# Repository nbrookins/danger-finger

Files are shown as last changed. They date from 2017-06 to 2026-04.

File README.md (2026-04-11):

# danger-finger
Source code for the DangerCreations danger-finger, a DIY 3D-printable prosthetic finger device.

This is a pre-release, in progress.  Use at own risk.  Latest stable version is available at: http://www.thingiverse.com/thing:1340624

You'll need to install Python3, and then once you have Python and Pip, do "pip3 install -r ./requirements.txt"
then simply run "python3 utility.py" to compile the project.  It will output a .scad file for each part as well as a composite "all".  If you add the -r flag ("python3 utility.py -r"), it will attempt to locate OpenSCAD on your machine, and render the SCAD files into STL.  Alternatively you can do this manually with each required scad file by performing RENDER and Export STL in OpenSCAD app.

-----------------------------------------------------------------------------------

The project is undergoing a major rewrite, from OpenSCAD to Python 3 + SolidPython2, a drastic improvement in reliable configuration to various shapes and sizes and needs as well as making the codebase easier to maintain and update.

For more information about how to build or have a prosthetic finger built, visit: http://dangercreations.com/prosthetics

**Docs**: [Parameters](docs/PARAMETERS.md) · [Product requirements and design decisions](docs/PRODUCT.md)

**G-code (Anycubic ACE / multi-tool)**: [tools/gcode-swap.py](tools/gcode-swap.py) post-processes exported `.gcode` to insert toolchanges on a repeating schedule (1–4 tools). Use `-n N` for the same layer thickness per color, or `--layers-per-tool n0,n1,…` for different counts per tool in cycle order (e.g. `--tools 0,1,2 --layers-per-tool 8,3,5`). It rewrites `paint_info` so **Color Match** sees distinct RGB swatches (from `extruder_colour` or `--tool-colors`). **Speed**: `--m220-percent` injects `M220 S…` after the first layer (firmware %); `--f-percent` or `--f-factor` scales every `F` feedrate in the executable block (bakes into G-code; composes with `M220` if both are set). **Temperature** (only between the first `;LAYER_CHANGE` and `; filament end gcode`, and only where `S>0` so cooldown is untouched): `--bed-temp`, `--tool-temps 220,225` or `0:220,1:225`. **Inspect**: `--inspect` prints layers, F/M220 stats, temps in that window, and colors. Other flags: `--dry-run`, `--no-flush`, `--no-wipe-tower`, `--no-patch-paint`, `--first-layer`, `--m220-reset-end`. Example: `python3 tools/gcode-swap.py -n 3 --no-flush plate.gcode -o plate_swapped.gcode`

**Web tests**: `make test-web` runs e2e against a fresh server. `make verify-web-ui` starts the server (Docker or local); the server builds SCAD + preview PNGs to `output/` at startup, then captures `output/viewer-screenshot.png`. Use `make build` first for Docker (avoids macOS OpenSCAD issues). For inspect only with an already-running app: `make inspect-ui` (writes `output/ui-inspect.txt`). Requires `pip install -r requirements-dev.txt`, `python -m playwright install chromium`, and OpenSCAD.

**Parametric QA loop**: Create a local env with `python3 -m venv .venv && .venv/bin/pip install -r requirements.txt -r requirements-dev.txt`. The curated first-wave profile matrix lives in `tests/profiles.py`. `make param-audit-scad` runs the multi-profile audit without STL rendering (useful on macOS when local OpenSCAD is broken). `make param-audit` adds STL + bbox checks, and `make param-audit-visual` also renders multi-view PNGs. The audit writes `output/param_audit/report.json` and `output/param_audit/report.md`.

**Auto-run on commit** (optional): To run web tests automatically when you commit changes under `web/`, install the hook: `cp scripts/pre-commit-web-test.sh .git/hooks/pre-commit && chmod +x .git/hooks/pre-commit`.

**OpenSCAD troubleshooting (macOS Apple Silicon)**:
- *"Incompatible processor... neon crc32"* or *"CGLChoosePixelFormat() failed"* — Run the server via Docker: `make build` then `make verify-web-ui`. The server runs in Docker and builds SCAD+PNGs at startup, avoiding macOS OpenSCAD/Qt issues.

#vscode and python extension
python3 -m ensurepip --upgrade
python3 -m pip install --upgrade pip
pip3 install -r ./requirements.txt
brew install docker
make

Run tests
--------

Install pytest if you don't have it already:

    pip3 install pytest

Run tests with:

    pytest -q

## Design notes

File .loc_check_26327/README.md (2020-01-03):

# danger-finger
Source code for the DangerCreations danger-finger, a DIY 3D-printable prosthetic finger device.

This is a pre-release, in progress.  Use at own risk.  Latest stable version is available at: http://www.thingiverse.com/thing:1340624

You'll need to install Python3, and then once you have Python and Pip, do "pip3 install SolidTools"
then simply run "python3 danger_finger.py" to compile the project.  It will output a .scad file, depending on flags and configuration.  By default, it will output all objects to a *preview.scad file.

To view the output install OpenScad from openscad.org, and open the scad file.  It can auto-preview, so that each time you compile the Pytyhon, you'll get an automatic preview.  

Lastly, RENDER the scad which will allow you to export an STL file for your printer.  In the future a web-interface and auto-render script will be provided for automating this part of the process.

-----------------------------------------------------------------------------------

The project is undergoing a major rewrite, from OpenSCAD to Python 3 + SolidPython, a drastic improvement in reliable configuration to various shapes and sizes and needs as well as making the codebase easier to maintain and update.

For more information about how to build or have a prosthetic finger built, visit: http://dangercreations.com/prosthetics

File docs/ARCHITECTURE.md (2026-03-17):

# Architecture

This document describes the system architecture of the danger-finger project: how user measurements become printable prosthetic finger STLs, and how the code is organized.

---

## System overview

```
User (browser)
  │  measurements / parameter values
  ▼
index.html + JS modules (api.js, params.js, viewer.js, app.js)
  │  POST /api/preview  or  POST /api/render
  ▼
server.py (Tornado, port 8081)
  │  config hashing, deduplication
  ▼
build() → DangerFinger.build()
  │  SolidPython2 CSG tree → scad_render() → .scad string
  ▼
Scad_Renderer.scad_to_stl()
  │  subprocess: openscad --export-format binstl -o part.stl part.scad
  ▼
.stl files (binary STL)
  │
  ├──(preview)──→ temp dir → served as /api/preview/temp/{run_id}/{part}.stl
  │
  └──(render)───→ bundle.zip (STL + SCAD + config + LICENSE + README)
                    → S3: render/{cfghash}/bundle.zip
                    → Lambda proxy for browser reads
```

---

## Class hierarchy

```
DangerFingerParams          (finger_params.py)
  │  ~80 Prop descriptors (user-facing parameters)
  │  ~20 computed properties (intermediate_width_, tip_radius, etc.)
  │  Preview config: _preview_position_offsets, _preview_rotate_offsets, etc.
  │  compute_preview_positions(), compute_preview_plug_instances()
  │  validate_params(), get_params()
  │
  ▼
DangerFingerBase            (finger_base.py)
  │  build() — iterates FingerPart enum, calls part_xxx(), applies transforms
  │  _part_composite() — assembles multi-part views (all, explode)
  │  scad_header() — $fa/$fs quality settings
  │  Custom primitives: rcylinder, rcube, rcubecyl, trim, flaredcyl, circular_text
  │
  ▼
DangerFinger                (finger.py)
  │  VERSION = 5.4
  │  Class constants: ANCHOR_OFFSET_DISTAL, TENDON_CUT_ROTATE, etc.
  │  PART_COLORS dict
  │  part_base(), part_tip(), part_middle(), part_linkage(), part_socket(),
  │  part_tipcover(), part_plug(), part_peg(), part_pins(), part_stand(), part_bumper()
  │  Shared primitives: knuckle_outer, knuckle_inner, bridge, bridge_anchor,
  │  socket_interface, tendon_hole, elastic_hole, tip_interface, link_hook, etc.
```

Supporting classes:

| Class | File | Role |
|---|---|---|
| `Prop` | `Params.py` | Descriptor enforcing min/max, metadata (docs, adv, hidden), getter/setter hooks |
| `Params` | `Params.py` | Static utility: CLI parsing, config open/save/apply, env var override |
| `Borg` | `Scad_Renderer.py` | Singleton pattern (shared `_shared_state` dict) |
| `Scad_Renderer(Borg)` | `Scad_Renderer.py` | OpenSCAD subprocess management, parallel rendering, multi-view PNG |
| `FingerServer(Borg)` | `server.py` | S3 client (boto3), brotli-compressed storage, config/profile/bundle CRUD |

Enums (`constants.py`):

| Enum | Type | Purpose |
|---|---|---|
| `Orient` | IntFlag | PROXIMAL, DISTAL, INNER, OUTER, UNIVERSAL, MIDDLE — composable orientation flags |
| `FingerPart` | IntFlag | SOCKET, BASE, MIDDLE, TIP, TIPCOVER, LINKAGE, PLUG, PEG, BUMPER, STAND, PINS, ALL, EXPLODE |
| `BumperStyle` | Enum | NONE, MINIMAL, COVER, FULL |
| `RenderQuality` | Enum | INSANE through STUPIDFAST — controls OpenSCAD $fa/$fs |
| `CustomType` | IntFlag | UI widget hints (SLIDER, DROPDOWN, etc.) |

---

## The Prop descriptor system

`Prop` is a Python descriptor that replaces `@property` for configurable parameters. It stores a default value and enforces min/max bounds on every `__set__`.

```python
class Prop:
    def __set_name__(self, owner, name):
        self.name = name

    def __set__(self, obj, value):
        if self._setter: value = self._setter(self, obj, value)
        setattr(obj, "__" + self.name, self.minmax(value, self._min, self._max))

    def __get__(self, obj, objtype=None):
        if obj is None: return self       # class-level access returns Prop itself
        if self._getter: return self._getter(self, obj, objtype)
        val = getattr(obj, "__" + self.name, None)
        return val if val is not None else self._value  # fall back to default
```

Key behaviors:
- Instance values stored as `obj.__paramname` (name-mangled to avoid collision)
- Class-level access (`DangerFingerParams.intermediate_length`) returns the `Prop` object (used by `get_params()` introspection)
- `get_params(adv=False, allv=True, extended=True)` iterates `Prop` descriptors via `inspect.getmembers` and returns metadata dicts for the frontend
- Custom setters handle enum conversion (e.g., `_bumper_style_setter` converts string to `BumperStyle`)

---

## Build pipeline

### 1. `DangerFingerBase.build()`

```python
for _, pv in FingerPart.__members__.items():
    name = str.lower(pv.name)
    self._parts[name] = self.part(pv)       # calls part_xxx() or _part_composite()
    # Apply print-orientation transforms
    if rotates and not isinstance(rotates, dict):
        temp = rotate(rotates)(temp)         # _rotate_offsets[name]
    if offsets and not isinstance(offsets, dict):
        temp = translate(offsets)(temp)       # _translate_offsets[name]
    temp = flatten(temp)
    self._models[name] = temp.render() if self.scad_render else temp
```

After the loop, a second pass renders each model to SCAD strings via `scad_render()` with quality header ($fa, $fs).

### 2. Per-part methods

Each `part_xxx()` method:
1. Constructs CSG primitives (cylinders, cubes, hulls)
2. Combines them additively and subtractively
3. Returns the final SolidPython2 object (not yet SCAD text)
4. The `build()` loop applies `.render()` which evaluates lazy CSG into a concrete tree

### 3. Print orientation

`_rotate_offsets` (dict of part name -> `(rx, ry, rz)`) rotate each part from its natural assembled orientation into optimal FDM print orientation. This happens in `build()` and affects the exported STL files.

The web viewer reverses this with `_preview_rotate_offsets` (approximate inverse rotations applied in the browser). See `docs/VIEWER_ASSEMBLY.md`.

### 4. SCAD rendering to STL

`Scad_Renderer.scad_to_stl()` calls OpenSCAD via subprocess:
```
openscad --enable manifold --export-format binstl -o part.stl part.scad
```

`scad_parallel()` runs multiple parts concurrently using `asyncio` with configurable `max_concurrent_tasks`. PNG previews can be generated simultaneously using `--preview --imgsize`.

---

## Server architecture

### Tornado handlers

| Route | Handler | Method | Auth | Purpose |
|---|---|---|---|---|
| `/` | `IndexHandler` | GET | No | Serves `index.html` with build-ID-stamped `?v=` cache busters |
| `/api/parts` | `ApiPartsHandler` | GET | No | Part list, version, build ID, preview config |
| `/api/preview` | `ApiPreviewHandler` | POST | No | Async preview: enqueues job at PRIORITY_PREVIEW=-10, returns 202 with job_id |
| `/api/render` | `ApiRenderHandler` | POST | Optional JWT | Queue a full render job; authenticated requests get higher priority |
| `/api/preview/temp/...` | `ApiPreviewTempHandler` | GET | No | Serve temp STL files from disk (local only, not S3) |
| `/jobs/{job_id}` | `JobStatusHandler` | GET | No | Job status: preview results from memory, render jobs from S3 |
| `/render/{cfghash}/status` | `RenderStatusHandler` | GET | No | Render status by content hash |
| `/params/...` | `FingerHandler` | GET | No | Parameter metadata (extended JSON) |
| `/profile/.../config/...` | `FingerHandler` | POST/DELETE | JWT | Save/remove config in S3 profile (ownership enforced) |
| `/profiles/...`, `/configs/...`, `/render/...` | `FingerHandler` | GET | No | S3 read fallback (primary is Lambda) |
| `/(*)` | `StaticHandler` | GET | No | Static files from `web/` |

### Preview vs render

- **Preview** (`/api/preview`): Returns 202 immediately. Job enqueued at PRIORITY_PREVIEW=-10 (always first). Worker runs EXTRAMEDIUM quality, writes STLs to temp dir, stores result in `application.preview_results` (in-memory dict, pruned after 10 min). Frontend polls `/jobs/{id}` until complete. No S3 persistence for preview jobs.
- **Save** (`/profile/.../config/...`): authenticated only. Saves config/profile metadata immediately and does not block on rendering.
- **Render** (`/api/render`): HIGH quality, durable async job that eventually writes `bundle.zip` to S3. Guests may render, but guest jobs are deprioritized and rate-limited.

Both preview and render jobs share the same worker queue. Preview jobs are in-memory only (`application.in_memory_jobs`); render jobs are additionally persisted to S3 for restart recovery. The module-level `_app_ref` provides access to application state from helper functions.

### Config hashing

`package_config_json()` removes default-value params, sorts keys, SHA-256 hashes the JSON. Identical configs always produce the same `cfghash`, enabling deduplication.

### S3 layout

```
configs/{cfghash}           — JSON config (brotli-compressed with "42" prefix)
profiles/{userhash}         — JSON profile with configs map (brotli)
jobs/{job_id}               — durable render job records for polling and restart recovery
render/{cfghash}/status     — latest render status payload for hash-based polling
render/{cfghash}/bundle.zip — ZIP containing STLs, SCADs, config.json, LICENSE, README
```

---

## Frontend architecture

Four vanilla JS modules loaded as global IIFEs (no bundler):

### `api.js` — HTTP client
- XHR-based, three base URLs: `baseurl` (default/relative), `readUrl` (Lambda reads), `renderUrl` (EC2 write/render API)
- `requestPreview()` debounced at 500ms; POST returns 202, frontend polls `/jobs/{id}` every 2s via `_pollPreview()`; superseded previews ignored via `_latestPreviewJobId`
- `saveConfig()` is authenticated profile persistence only; `renderConfig()` queues full renders for guests or logged-in users
- `fetchRenderStatus()` / `fetchJobStatus()` poll durable status through the read path
- `fetchBundleZip()` uses `arraybuffer` responseType for JSZip extraction
- Network errors (status 0) on render endpoints show "server offline" message

### `params.js` — Parameter form
- Renders parameter table from `/params/all` metadata in three sections: Common (params with `Section === "common"`), Standard, and Advanced (collapsible)
- Preset configurations dropdown above Common section (Adult index, Adult pinky, Child index, Adult thumb)
- Per-param reset button (×) shown on modified rows; global "Reset all to defaults" link
- Tracks dirty (unsaved) and changed (differs from default) states per param
- `setRenderDisabled()` controls render button independently from save
- `getCurrentParams()` returns current form values as `{name: numericValue}` dict

### `viewer.js` — 3D viewer manager
- Wraps `StlViewer` (Three.js r160 compatibility wrapper)
- Manages part ID -> mesh mapping, plug instances (IDs 100-103), explode slider
- `applyPreviewConfig()` sets positions/rotations/explode offsets from server
- `updateFromStlUrls()` removes all models and re-adds from new URL map
- `PREVIEW_SKIP_PARTS = { "pins": true }` — pins excluded because composite STL cannot be correctly positioned

### `app.js` — Orchestrator
- Initializes all modules, wires callbacks
- Manages guest draft persistence across the WordPress login redirect via `sessionStorage`
- Splits authenticated `Save` from guest-capable `Render`, polls queued jobs, and resumes save after login
- Render button intelligence: tracks `_lastRenderedCfghash`, disables button when config matches last render
- Iframe detection: shows "Open full page" button when embedded; "Share link" encodes params in URL hash
- `restoreFromHash()` loads config from `#config=...` URL hash on page load
- Profile table includes Status column (Saved/Rendering.../Ready) with polling for active renders
- Quality indicator in preview status: "(draft quality)" vs "(print quality)"
- `loadBundleZip()` fetches ZIP via Lambda, extracts STLs with JSZip, and creates blob URLs

### `stl_viewer.js` — Three.js wrapper
- Compatibility wrapper over Three.js r160 + STLLoader r170 + OrbitControls r170
- Replicates the exact `StlViewer` API used by `viewer.js`
- Transform pipeline: load STL -> bbox center -> rotate (world-axis X/Y/Z) -> set position
- See `docs/VIEWER_ASSEMBLY.md` for transform semantics

---

## Docker

`docker/Dockerfile` is based on `openscad/openscad:trixie.2025-12-15` (Debian with OpenSCAD pre-installed). Python 3 venv with solidpython2, tornado, boto3, brotli. Entry point runs `server.py`.

The container serves both the web UI and performs OpenSCAD rendering. No separate worker process.

---

## Testing infrastructure

| Target | Script | What it tests |
|---|---|---|
| `make test-web` | `scripts/test_web.sh` | Fresh local server, hits /, /api/parts, POST /api/preview |
| `make kbr-test` | Makefile inline | Docker build + run + test |
| `make verify-web-ui` | `scripts/verify_web_ui.sh` | Docker container + Playwright screenshot |
| `make inspect-ui` | `scripts/inspect_ui.py` | Playwright against running server |
| `make reference-stls` | `scripts/reference_stls.py` | Build baseline STL checksums |
| `make regression-check` | `scripts/regression_check.py` | Compare current STLs to baseline |
| `make validate-formula` | `scripts/validate_formula.py` | Sweep params, check geometry |
| `pytest` | `tests/test_*.py` | Unit tests: param sweep, boundary, smoke |

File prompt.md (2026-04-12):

# DangerFinger

Parametric prosthetic finger — a customizable, 3D-printable mechanical finger prosthesis. Users configure parameters through a web UI, preview the assembled model in a Three.js viewer, and download STL files for printing.

## Stack

- **Geometry**: Python + SolidPython2 → OpenSCAD SCAD → STL
- **Web**: Tornado server, Three.js viewer, Playwright for automated visual testing
- **Deploy**: Docker image on EC2 (via ECR), static assets on S3 + CloudFront
- **Testing**: pytest, SCAD hash baselines, parameter sweep audits, multi-angle Playwright screenshots

## Key Entry Points

| Task | Command |
|---|---|
| Start dev services | `make start-dev` (run once in terminal) |
| Run all tests (local) | `make test-parametric` |
| Run fast tests only | `make test-parametric-fast` |
| Start local server | `make serve-local` |
| Visual review only | `make visual-review` (needs running server) |
| Build Docker image | `make build` |
| Deploy to AWS | `make deploy` |

## Testing Philosophy

- **Local-first**: All testing runs natively. Docker is only for deploy.
- **Dev-server pattern**: Run `make start-dev` once in a terminal — this starts an OpenSCAD render server and headless Chromium outside the Cursor sandbox. The pipeline connects via localhost, so all 3 tiers run with zero sandbox prompts.
- **OPENSCAD_EXEC**: Set to `bin/openscad-local` which POSTs to the dev-server's OpenSCAD endpoint. Fallback: `bin/openscad-docker`.
- **Tiered validation**: Tier 1 (fast, no OpenSCAD), Tier 2 (STL render + bbox), Tier 3 (visual web UI via CDP).
- **Artifacts**: `output/parametric-report.md`, `output/visual-review/report.html`, `output/viewer-screenshot.png`.

## Project Structure

- `danger/` — parametric model (finger_params.py, finger.py, finger_base.py, Scad_Renderer.py)
- `web/` — Tornado server + Three.js viewer (server.py, viewer.js, stl_viewer.js)
- `scripts/` — automation (parametric_report.py, visual_review.py, param_audit.py, verify_web_ui.sh)
- `tests/` — pytest suite (param sweeps, profile tests, geometry checks)
- `bin/` — CLI wrappers (openscad-docker)
- `docker/` — Dockerfile + entrypoint for production image
- `infra/` — Terraform for AWS infrastructure
- `docs/` — architecture, deploy, parameters, viewer assembly docs

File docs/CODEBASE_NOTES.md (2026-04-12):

# Codebase Notes

Learnings discovered during SCAD optimization and customizer planning (2026-03-12).

## Geometry and rendering

- `finger.py` contains 12 `part_*` methods and ~38 helper functions (~780 lines)
- `finger_params.py` defines 93 `Prop` parameters (plus 1 in `finger.py`: `peg_hollow_radius`)
- Render quality uses `$fa`/`$fs` globally (set in SCAD header), NOT `$fn`
  - SolidPython2's `_fn=` parameter emits per-primitive `$fn=` which overrides the global setting
  - Mixed `$fn` and `$fa/$fs` can produce visual seams at primitive boundaries
  - Only use `_fn=` on cutting geometry (invisible in final output) or hull anchors (too small to see)
- `RenderQuality.EXTRAHIGH` (value 8) exists in `constants.py` but has NO mapping in the `fs_` or `fa_` dicts in `finger_params.py` -- using it will cause a `KeyError`

## Known hotspots

- `_socket_bottom()` (line 460): loop runs `socket_depth` (default 34) individual `rotate_extrude()` calls -- the #1 render-time hotspot
- `part_tipcover()` fingerprints (line 366): ~19 individual cube subtractions from a sphere
- Bridge/tunnel system (`create_bridge`, `make_bridge`): most complex CSG geometry, uses multi-sphere hulls with small anchor spheres

## Parameter system

- `Prop` class in `Params.py` supports: val, minv, maxv, doc, adv (advanced), hidden, custom (CustomType), setter
- `CustomType` enum (DROPDOWN, SLIDER, SPINNER, CHECKBOX, TEXTBOX) exists but is only used by the web UI, not for SCAD output
- `Params.open_config` does direct `params[k] = config[k]` with no migration path -- if a Prop name changes, saved configs silently fall back to defaults
- No preset/sizing infrastructure exists; must be built from scratch

## Regression testing

- `scripts/regression_check.py` uses exact SHA-256 hashes of STL files
- `scripts/reference_stls.py` generates reference STLs at default params
- Any change to tessellation (quality settings, $fn overrides) will change hashes even when geometry intent is unchanged
- For optimization work, need geometry-aware validation (bounding box, volume, visual diff)

## Magic number audit (Pass 2, 2026-04-11)

Class-level constants in `DangerFinger` and inline literals in `part_*` methods.

### Derived (applied)

| Constant | Old value | New formula | Status |
|---|---|---|---|
| `SCALLOP_HEIGHT` | `9` | `socket_bottom_cut` (property) | Applied. Exact match at defaults. **Visual review needed at extreme socket_bottom_cut** (0–60). |

### Derivation candidates (need visual review before applying)

| Constant | Value | Candidate formula | Match at defaults | Notes |
|---|---|---|---|---|
| `PEG_SUPPORT_RADIUS` | 1.2 | `tendon_hole_radius + 0.1` | Exact (1.2) | Support sleeve around peg hole; would scale with tendon size |
| `PEG_SUPPORT_SIDE_X_OFFSET` | 1.65 | `tendon_hole_radius * 1.5` | Exact (1.65) | Side support spread; proportional to tendon path |
| `PEG_SUPPORT_TRANSLATE_Z` | 3.4 | No clean formula | N/A | Closest: `tendon_hole_width * 1.545` — not clean enough |
| `ANCHOR_OFFSET_DISTAL` | -0.485 | No clean formula | N/A | Closest: `-(knuckle_clearance * 0.5 + knuckle_side_clearance)` = -0.42 |
| `TENDON_CUT_ROTATE` | -80 | Fixed angle | N/A | Empirically tuned cut angle for tendon routing |
| `SOCKET_RIDGE_SPACING_FACTOR` | 0.0015 | Fixed factor | N/A | Controls ridge texture density; print-tolerance dependent |
| `SOCKET_BOTTOM_CUT_FACTOR` | 1.2 | Fixed factor | N/A | Scales bottom cut radius; likely print-tolerance dependent |
| `SCALLOP_RADIUS_ADJ` | 1 | Fixed offset (mm) | N/A | Scallop oversizing; may relate to wall thickness |
| `TIP_FIST_TRIM_ROTATE` | -25 | Fixed angle | N/A | Range-of-motion clearance; empirically tuned |

### Inline method literals (not yet promoted to constants)

| Location | Value | Description | Candidate |
|---|---|---|---|
| `part_base` | `breather_radius_factor=0.2` | Breather hole proportion | Could be Prop if user-meaningful |
| `part_base` | `breather_height=20` | Subtractively long | Could be `socket_depth + margin` |
| `part_base` | `breather_translate_y=-10` | Alignment offset | Likely `-(socket_interface_length + margin)` |
| `part_tipcover` | `TIP_CORE_RESIZE_INSET=2` | Flattening of tip sphere | May relate to `tip_radius` |
| `tip_interface` | `tipcover_chamfer=0.6` | Interface chamfer depth | Could relate to `tipcover_thickness` |
| `part_middle` | `-3.75` in `anchor_db` | Bottom strut Y offset | Likely `-(distal_base_length * 0.625)` at defaults |
| `part_middle` | `1.3` in bumper translate | Bumper X centering | Empirical; tracks hinge radius offset |
| `bridge_anchor` | `-.5` in `height_bottom` | Strut clearance | Small tolerance offset |
| `knuckle_inner` | `1.0` in `anchor_b` Y | Bottom anchor Y nudge | Likely related to clearance |

## Downstream consumers of part output

- `web/server.py` treats stand as a standard part in render/preview flows
- `scripts/generate_static.py`, `scripts/reference_stls.py`, `scripts/regression_check.py`, `scripts/validate_formula.py` all iterate over parts
- Stand exclusion in native SCAD means "don't port it" but keep generating it from Python pipeline

## Existing infrastructure

- `benchmark-ec2` Makefile target exists for cloud benchmarking (no local render-timing target)
- `validate-formula` target exists for parameter sweep validation
- `regression-check` target for STL comparison
- `output/` directory exists and is used for build artifacts

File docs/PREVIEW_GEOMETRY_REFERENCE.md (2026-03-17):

# Preview Geometry Reference

Canonical reference for 3D preview part positioning. Consult before changing any offsets.

## Coordinate system

- **Y** = finger long axis (proximal hinge = Y≈0, distal hinge = Y≈int_len)
- **X** = forward/back (positive = toward palm/front, negative = toward back of hand)
- **Z** = left/right (lateral axis, hinge pin direction)

## Current offsets (default params, int_len=24)

| Part | X | Y | Z | Notes |
|---|-----|---|-----|---|
| socket | 0 | -26  | 0 | Large cylindrical socket, wraps around base bottom |
| base | 0 | -4 | 0 | Proximal hinge at top (Y≈0) |
| middle | 0 | 11 | 0 | Spans proximal→distal hinge, struts + cross-members |
| tip | 1 | 26 | 0 | Distal hinge at bottom (Y≈24), X=1 for slight forward offset |
| tipcover | 0 | 38 | 0 | Dome cap on top of tip |
| linkage  | 0 | -3 | 20  | Tendon routing channel, spans full finger on Z side |
| stand | 0 | -45  | 0 | Display stand, hidden by default |
| bumper | 0.5 | 11 | 0 | TPU ring around middle section; X tested: 0=too back, 0.5=flush, 1=tiny protrude back, 2=too forward |
| plug | inst | inst | inst | 4 instances at hinge faces (see below) |

## Plug instances

| Instance | X | Y  | Z | Rotation |
|---|---|-----|---|---|
| Proximal left  | 0 | 0 | -8.6  | (0, 0, 0) |
| Proximal right | 0 | 0 | 8.6 | (0, 180, 0) |
| Distal left | 0 | 24  | -7.4  | (0, 0, 0) |
| Distal right | 0 | 24  | 7.4 | (0, 180, 0) |

Plugs sit at Y=0 (proximal hinge) and Y=int_len (distal hinge). No Y nudge.

## SCAD-derived bbox centers (ground truth for default params)

Computed by applying inverse-print-rotation to native STL vertices + SCAD "all" offsets:

| Part | SCAD X | SCAD Y | SCAD Z |
|---|---|---|---|
| socket | 0.0 | -25.9  | 0.0 |
| base | 0.5 | -3.9 | 0.0 |
| middle | 1.0 | 11.6 | 0.0 |
| tip | 1.2 | 26.3 | 0.0 |
| tipcover | 0.0 | 39.0 | 0.0 |
| linkage  | 0.1 | -3.1 | 20.0 |
| stand | 0.0 | -45.1  | 0.0 |
| bumper | 0.0 | 0.0 | 0.0 |

Note: bumper SCAD center is (0,0,0) because in SCAD it's at the proximal hinge origin.
In the web viewer, bumper must be at middle_y to wrap around the struts after geometry.center().

## Alignment rules

1. **Bumper X must match middle X.** Both wrap the same strut section. If middle moves on X, bumper follows.
2. **Tip X=1** gives a slight forward lean that matches the hinge geometry. Reducing to 0 makes the tip appear recessed.
3. **Hinge overlaps (5-10mm) are natural.** Fork/socket geometry interleaves at each joint. Don't try to eliminate.
4. **Tipcover sits flush on tip.** The gap between tip Y and tipcover Y should be ~12mm (half of each part's Y extent).
5. **Socket/base overlap is expected.** Socket wraps around the base; the top of socket extends up to near the proximal hinge.

## Rotated bounding box dimensions (after center + preview rotation)

| Part | Y half-height | Total Y extent |
|---|---|---|
| socket | 20.4 | 40.9 |
| base | 9.4 | 18.8 |
| middle | 17.1 | 34.2 |
| tip | 7.1 | 14.2 |
| tipcover | 9.0 | 18.0 |
| bumper | 1.8 | 3.5 |
| stand | 18.1 | 36.3 |
| linkage  | 38.1 | 76.1 |
| plug | 3.2 | 6.4 |

## Change log

| Date | Part(s) | Change | Reason |
|---|---|---|---|
| 2026-03-17 | all | Derived from SCAD part_all | Replace manual guesses with measured values |
| 2026-03-17 | plugs | Removed +1.5mm Y nudge | Plugs were sitting above hinge holes |
| 2026-03-17 | middle | X: 1→0, Y: 12→11 | X protrusion visible from side; gap with base |
| 2026-03-17 | tip | Y: 27→26 | Over-correction squeezed tip between middle and cover |
| 2026-03-17 | tipcover  | Y: 39→38 | Slight gap with tip |
| 2026-03-17 | bumper | X: 2→0→1→0.5 | Tested from back view: X=2 protrudes forward, X=0 protrudes back, X=1 tiny back protrude, X=0.5 flush |

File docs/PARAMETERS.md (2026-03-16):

Parametrized magic numbers
==========================

Several hardcoded numbers in `danger/finger.py` were made configurable via `DangerFingerParams` so you can tune behavior without editing source.

Added parameters (defaults chosen to preserve current behavior):

- `proto_shell_sphere_radius` (default 5)
- `proto_shell_sphere_y_factor_a` (default 3.5)
- `proto_shell_sphere_y_factor_b` (default 10.0)
- `proto_shell_sphere_z` (default 9)
- `proto_shell_cut_cube_x`, `proto_shell_cut_cube_y`, `proto_shell_cut_cube_z` (defaults 30,20,30)
- `proto_shell_cut_translate_y` (default -35)
- `tip_proto_cube_x`, `tip_proto_cube_y`, `tip_proto_cube_z` (8,20,20)
- `tip_proto_translate_x_offset` (default 7)
- `tip_proto_bottom_cut_*` (defaults 10,50,30 and translate_x_offset -0.5)
- `cut_fist_radius_offset`, `cut_fist_h`, `cut_fist_scale_y`, `cut_fist_translate_y1`, `cut_fist_translate_y2`, `cut_fist_translate_z`, `cut_fist_rotate` (control the fist cut geometry)
- `bridge_cut_a_y_offset`, `bridge_cut_b_y_offset`, `bridge_ledge` (control bridge cut translations and ledge)

Usage
-----

Adjust parameters either programmatically (e.g. `finger.proto_shell_sphere_radius = 8`) or through any provided GUI/parameter interface before rendering to experiment with variants.

Preview vs print orientation
----------------------------

- **`_rotate_offsets`** (in `danger/finger_params.py`): Applied at export so STLs are in print orientation for slicing. Do not change for preview display.
- **`_translate_offsets["all"]`**: Used by part_all and assembly; do **not** use for viewer layout or you will break the all.stl output.
- **`_preview_position_offsets`**: Viewer-only positions (part name → (x,y,z)). Used only by the web API for preview; part_all and STL export are unchanged. Proximal→distal along +Y; linkage behind finger (-Z). Tune here to fix stacked preview without touching `_translate_offsets`.
- **`_preview_rotate_offsets`**: Per-part (rx, ry, rz) in degrees applied only in the web viewer so the same STLs appear as an assembled finger. Tune these if preview alignment looks wrong. `middle` is set to `(-90, 50, -90)` (approximate inverse of its print rotation `(90, -50, 90)`; see `docs/VIEWER_ASSEMBLY.md` section 6).
- **`_preview_hidden`** *(planned)*: Set of part names (e.g. `{"stand"}`) hidden by default in the preview UI.
- **`_preview_plug_instances`**: List of four `{ "position": (x,y,z), "rotation": (rx,ry,rz) }` entries for the four plug instances (proximal L/R, distal L/R). Same plug STL is shown four times in the viewer at these positions/rotations so plugs appear in their tip holes.
- **`_preview_position_override`** *(planned)*: Optional overrides on top of `_preview_position_offsets` for a single part (viewer only).

Parameter ordering and sections
-------------------------------

Parameters are displayed in three sections via the `section` and `order` attributes on `Prop`:

- **Common** (`section="common"`): Most-used sizing params shown first in a highlighted section. Order determines display position within the section.
- **Standard** (no section, `adv=False`): All other non-advanced params, sorted by order then name.
- **Advanced** (`adv=True`): Collapsed by default, for parameters that affect print fit.

`get_params()` sorts by `(section_rank, order, name)` where `section_rank` is 0 for "common" and 1 for everything else. The API response includes `Section` and `Order` fields in extended mode.

| Param | Section | Order | Rationale |
|---|---|---|---|
| `intermediate_length` | common | 1 | Primary sizing param |
| `socket_circumference_proximal` | common | 10 | Socket fit (widest) |
| `socket_circumference_distal` | common | 11 | Socket fit (narrow end) |
| `socket_depth` | common | 12 | Socket depth |
| `distal_length` | common | 20 | Tip segment length |
| `distal_base_length` | common | 21 | Tip base length |

All other standard params keep `order=100` (default). Advanced params keep `adv=True`.

Notes
-----

These changes are intentionally conservative: defaults reproduce prior behavior. If you'd like I can continue and parameterize additional hardcoded values (nail cut offsets, tunnel helper constants, and more).

---

See also
--------

- [Architecture](ARCHITECTURE.md) — system pipeline, class hierarchy, build flow
- [Parts Anatomy](PARTS_ANATOMY.md) — physical design of each part and known TODOs
- [CSG Patterns](CSG_PATTERNS.md) — SolidPython2 idioms and custom primitives
- [Viewer Assembly](VIEWER_ASSEMBLY.md) — how the web viewer positions and rotates parts
- [Product](PRODUCT.md) — product requirements and design decisions

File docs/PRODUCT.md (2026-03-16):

# Product requirements and design decisions

This document is the running record of product requirements and design decisions for the Danger Finger project. Update it as the product and architecture evolve.

---

## Product requirements

### Goals

- **Web UI**: View and configure the finger prosthetic (STL) in the browser, change parameters with live preview, filter parts, and save/load configs (with auth where needed).
- **Backend**: Support both quick preview (ephemeral, no S3) and full render (stored in S3); keep operations synchronous with a reasonable timeout (e.g. ≤10 s) and run OpenSCAD on the server (not Lambda).
- **Profiles**: Users can save configs under a profile; profile stores config name → cfghash and history for save-in-place and history.

### User-facing features

- 3D viewer for finger parts (tip, middle, base, linkage, etc.) with part visibility toggles (e.g. checkboxes).
- Parameter form: standard parameters visible by default; advanced parameters in a separate section below when “Advanced” is selected. Parameters show descriptions (from API) and feedback for modified values.
- Explode slider: when non-exploded, parts are positioned as assembled (preview position); when exploded, parts move along explode offsets. Same STLs throughout.
- Save config: name and save under current user profile; triggers sync render and stores bundle.zip (STL + SCAD + config + LICENSE + README) in S3. Download link shown on completion.
- Load saved config: fetches bundle.zip from S3 via Lambda, extracts STLs client-side with JSZip, feeds to viewer. Download reuses cached ZIP blob.
- Remove saved configs from profile list.
- Download ZIP: available per-row in saved configs table and after save/load. Same `render/{cfghash}/bundle.zip` object used for viewer load and download — no re-fetch.
- Preview: on param change (debounced), request preview; viewer updates from temp STL URLs. No S3 for preview.

### Authentication

The app integrates with the WordPress site (dangercreations.com) for user identity.
Anonymous users can preview the finger and download public configs.
**Saving configurations and triggering full renders require a logged-in WordPress user.**

Auth flow:
1. User clicks "Log in" → redirected to `wp-admin/authorize-application.php` on WordPress.
2. WordPress authenticates the user (existing session or login prompt), then redirects back to the app with an Application Password.
3. App exchanges the Application Password for a JWT via `POST /wp-json/jwt-auth/v1/token`.
4. JWT stored in `sessionStorage`; `Authorization: Bearer <JWT>` header sent on all protected requests.
5. Tornado validates the JWT locally using the shared `JWT_AUTH_SECRET_KEY`; no WP round-trip per request.
6. Profile key = `user_nicename` from JWT payload (added via WP filter in `functions-auth.php`).

Protected endpoints (require valid JWT; return 401 with `auth_required: true`):
- `POST /api/render`
- `POST /profile/{userhash}/config/{cfg}` — also enforces that `userhash == jwt.user_nicename`
- `DELETE /profile/{userhash}/config/{cfg}` — same ownership check

Public endpoints: `GET /api/parts`, `GET /api/preview`, `GET /params/*`, `GET /profiles/*`, `GET /configs/*`, `GET /render/*`.

Setup: see `wordpress/dangerfinger-setup/README.md` for WordPress plugin installation,
`wp-config.php` additions, `.htaccess` Authorization passthrough, and PHP filter code.

### Non-goals / later

- Automated cleanup of dereferenced S3 objects (optional later).
- OpenSCAD WASM rendering in Lambda (blocked: openscad-wasm lacks Manifold, 100-660x slower than native).

---

## Design decisions

### Backend

| Decision | Rationale |
|---|---|
| **Async preview via job queue** | Preview now enqueued at PRIORITY_PREVIEW=-10 (always first) in the shared render queue, results stored in-memory (pruned after 10 min), frontend polls via /jobs/{id}. Eliminates the 10s timeout error for slow previews. |
| **OpenSCAD on server (not Lambda)** | Docker image already has OpenSCAD; avoids cold starts and payload limits. Container writes to S3; reads go through Lambda. |
| **Preview STLs in temp dir, not S3** | Previews are ephemeral; avoid S3 churn and cost. |
| **ZIP-only storage: `render/{cfghash}/bundle.zip`** | Single compressed object per config containing all STLs, SCAD, config JSON, LICENSE, README. Used for both viewer load (JSZip extraction in-browser) and download. 63% less storage, 33% less egress, 85% fewer requests vs individual STLs. cfghash immutability means no invalidation needed. |
| **Lambda for S3 reads (API Gateway + Lambda)** | Protects AWS credentials from client. Single Python handler with path-based routing: `/configs/{cfghash}`, `/profiles/{userhash}`, `/render/{cfghash}/bundle.zip`. Presigned URL redirect for ZIPs > 5 MB. SAM template at `template.yaml`. |
| **Profile stores `configs[name] = { cfghash, history }`** | Save-in-place and history without storing full config blob in profile. |
| **`/api/params` and `/api/params/all`** | Explicit routes for parameter definitions; frontend uses these instead of legacy `/params` regex route. |
| **`DangerFinger().params()` as a method (not property)** | Server needs to call `params(adv=..., allv=..., extended=True)`; property cannot take arguments. |
| **Print orientation vs preview display** | STLs are exported in print orientation (rotate_offsets) for slicing. Preview applies preview_rotate_offsets and preview position/explode in the viewer only; no duplicate STLs. |
| **`/api/parts` returns preview config** | Each part includes preview_position, explode_offset, preview_rotation (degrees), and hidden_in_preview so the viewer can display parts as an assembled finger and support explode without changing STL files. Plug is expanded to plug_0..plug_3 (same STL via `stl_part`); linkage uses a preview-only position override so it appears behind the finger/socket. |
| **stl_viewer centers geometry by default** | `stl_viewer.js` calls `geometry.computeBoundingBox()` + `translate(-center)` on load, moving the bbox center to the local origin (replicates old `geometry.center()` behavior). `_preview_position_offsets` must therefore specify the assembled-space bounding box center of each part. See `docs/VIEWER_ASSEMBLY.md`. |
| **stl_viewer rotates around world axis** | `add_model` uses `mesh.rotateOnWorldAxis(axis, angle)` X→Y→Z (world-space pre-multiply, equivalent to old `rotateAroundWorldAxis`). With geometry centered at origin, this rotates each part around its own center. Position from `mod_loaded` is set after rotation. |
| **preview_position_offsets fixed for v5.2+ print rotations** | Positions updated to assembled bbox centers measured from v5.1 STLs. Previously all zeros causing parts to overlap at viewer origin. See `docs/VIEWER_ASSEMBLY.md` section 3.2. |
| **SCAD all reference uses preview_rotate=False** | `preview_rotate = False` is hard-coded. `_part_composite` does NOT apply `_rotate_offsets["all"]`. The all.png is the assembled-orientation reference. |
| **OpenSCAD ARM64 workaround** | On macOS ARM64, Qt runtime check fails. Fix: prepend `arch -x86_64` in `Scad_Renderer.py` (Rosetta). `OPENSCAD_USE_ROSETTA` env var. Headless PNG needs Xvfb. |

### Authentication

| Decision | Rationale |
|---|---|
| **WordPress Application Passwords → JWT exchange** | User authorises the app via WP's built-in `authorize-application.php` (no custom plugin for the OAuth step). The returned Application Password is used exactly once to get a JWT, then discarded. JWT is stored in sessionStorage and validated locally — no per-request WP call. |
| **JWT Authentication for WP REST API plugin** | Standard, well-maintained plugin for issuing JWTs from WP. Secret shared with Tornado via `jwt_secret` env var. |
| **user_nicename as profile key** | WP user_nicename is stable (unlike display name) and URL-safe. Added to JWT payload via `jwt_auth_token_before_sign` filter so Tornado can read it without a WP API call. |
| **Auth disabled in dev (jwt_secret unset)** | When `jwt_secret` env var is empty, `auth.py` accepts any Bearer token and returns a guest payload. Allows local dev without a live WP site. |
| **Profile ownership check on writes** | Tornado verifies that `jwt.user_nicename == userhash` in the URL before writing. Prevents authenticated user A from overwriting user B's profile. |
| **PyJWT >= 2.0** | Version 2.x API (`decode` with `algorithms=[]` required, `options={"verify_aud": False}` for WP plugin). `requirements.txt` pins `PyJWT>=2.0`. |

### Frontend

| Decision | Rationale |
|---|---|
| **JSZip for viewer load from bundle.zip** | Load config fetches single ZIP via Lambda, extracts STLs in-browser (~30-50 ms), creates blob URLs for Three.js viewer. Same blob reused for download — zero re-fetch. |
| **Dual base URLs (`baseurl` / `readUrl`)** | Write operations (preview, save) go to Tornado container. Read operations (configs, profiles, render bundles) go to Lambda via API Gateway. Fallback: `readUrl` defaults to `baseurl` when Lambda is not deployed. |
| **Part visibility via checkboxes** | Clearer than toggle buttons; re-show part using `last_stl_urls` so toggling back on uses current preview URL. |
| **Parameters: Common → Standard → Advanced sections** | Most-used sizing params (6 tagged `section="common"`) appear first in a highlighted "Common" section; standard params follow; advanced params remain collapsed. Deterministic ordering via `Prop.order` and `Prop.section`. |
| **Preset configurations** | Dropdown above Common section with 4 presets (Adult index, Adult pinky, Child index, Adult thumb). Applies common param values and triggers preview. |
| **Per-param and global reset** | Each modified row shows an × button to reset that param to default; "Reset all to defaults" link resets everything. |
| **Render button intelligence** | Render button tracks `_lastRenderedCfghash`; disabled when current config matches last render; re-enabled on param change. Labels: Render / Rendering... / Queued... / Rendered. |
| **Full-page launch and share links** | "Open full page" button shown in iframe context; "Share link" button encodes params in URL hash, copies to clipboard. URL hash restored on load. |
| **Profile table status** | Status column shows Ready/Rendering.../Queued.../Saved per config, with polling for in-progress renders. |
| **Quality indicator** | Preview status shows "(draft quality)" or "(print quality)" based on whether current config has been rendered. |
| **Parameter descriptions from API** | API returns `Documentation` (from param docs); shown as tooltip and optional short description under label. |
| **Modified feedback (badge + row highlight)** | Users can see which params differ from default. |
| **Viewer errors surfaced in UI** | `#viewer_error` and `set_viewer_error()`; try/catch and `stl_viewer.error` reported in status so failures are visible. |
| **Request preview from viewer `ready_callback`** | First preview runs after viewer is ready so models load correctly. |

### DevOps / testing

| Decision | Rationale |
|---|---|
| **`make kbr-test`** | Build, run container in background, then run e2e test against it so we test the real Docker stack. |
| **`USE_EXISTING_SERVER=1` in test script** | Allows hitting an already-running server (e.g. Docker on 8081) without starting a second process. |
| **Test port 8091 when starting server in script** | Avoids clashing with Docker on 8081. |
| **`make inspect-ui` (Playwright)** | Headless browser loads the live UI, captures `#preview_status`, `#viewer_error`, and console; writes `output/ui-inspect.txt`. Exit 1 if the UI shows an error. Use when debugging “error and no preview” or to capture exactly what the page shows. Requires `pip install -r requirements-dev.txt` and `python -m playwright install chromium`. |

---

## Infrastructure & Deployment

The application deploys to AWS using Terraform-managed infrastructure. See [DEPLOY.md](DEPLOY.md) for full details.

**Components**: EC2 (Docker + OpenSCAD, handles writes), Lambda + API Gateway (read-only S3 API), S3 (persistent storage), ECR (image registry).

**Key files**: `infra/*.tf` (Terraform), `.github/workflows/deploy.yml` (CI/CD), `scripts/verify_aws_deploy.sh` (smoke tests), `scripts/aws_audit.py` (account audit), `scripts/benchmark_ec2.py` (instance benchmarking).

**Cursor rules**: `.cursor/rules/aws-deploy.mdc` (deployment safety), `.cursor/rules/terraform-conventions.mdc` (Terraform style). **Skill**: `.cursor/skills/deploy-to-aws/SKILL.md`.

---

## Changelog

- **2026-03** – UX overhaul: async preview queue (preview jobs processed at highest priority, polled by frontend), deterministic parameter ordering with Common/Standard/Advanced sections, render button intelligence (disabled when config matches last render), iframe full-page launch and shareable config links via URL hash, profile table render status column (Saved/Rendering/Ready), per-parameter and global reset-to-defaults, draft vs print quality indicator in viewer status, and preset configurations dropdown (Adult index, Child index, Adult pinky, Adult thumb). New Prop attributes: `order` and `section` for deterministic param display.
- **2026-03** – Anonymous access, authenticated save, durable render queue: WordPress now embeds the configurator for guests, while login is only required to save to a profile. Full renders submit through a durable S3-backed job queue with authenticated-first priority, guest throttling, job polling by `job_id` or `cfghash`, and restart recovery that requeues interrupted work after watchdog/container restarts. Frontend save and render are now separate actions, guest draft state survives the WordPress login redirect, and completed bundles remain downloadable without re-rendering.
- **2026-03** – Monitoring and auto-recovery: added CloudWatch-based EC2 system recovery, a scheduled health-check Lambda that probes `GET /api/parts`, automatic SSM container restart attempts, SNS email alerting, and operator commands for checking health/alarm state.
- **2026-03** – WordPress JWT authentication integration. Login via WP `authorize-application.php` → Application Password → JWT exchange. JWT validated locally in Tornado (`web/auth.py`, `WpAuthMixin`). Protected endpoints: `POST /api/render`, `POST /profile/*/config/*`, `DELETE /profile/*/config/*`. Profile ownership check (user can only write their own profile). Auth UI in app header (login/logout button, user display). `user_nicename` added to JWT payload via WP filter (`wordpress/dangerfinger-setup/functions-auth.php`). WordPress security hardening: user enumeration disabled, EXIF stripped, open registration blocked, `readme.html` blocked. CORS tightened to `WpAuthOrigin` parameter. `PyJWT>=2.0` added to `requirements.txt`. New env vars: `jwt_secret`, `wp_auth_url`, `app_base_url`. See `wordpress/dangerfinger-setup/README.md`.
- **2026-03** – AWS deployment infrastructure: audited and cleaned stale ECS/CloudFormation resources (~$20-26/mo savings), created Terraform configs (VPC, ECR, EC2, Lambda, API Gateway, S3, IAM, optional Route53/ACM), Makefile deploy targets, GitHub Actions CI/CD with OIDC, deployment verification scripts, and Cursor rules/skills. EC2 uses IAM instance profile (no static keys); server.py falls back to default credential chain; app.js reads `window.__READ_URL__` injected at serve time.
- **2026-03** – Save/load/download workflow and Lambda S3 access. Render now produces a single `render/{cfghash}/bundle.zip` containing all STLs, SCAD files, config JSON, LICENSE, and README — no individual STL files in S3. Frontend uses JSZip to extract STLs in-browser for viewer load; same cached blob serves as download (zero re-fetch). Save endpoint returns cfghash so frontend can show immediate download link. Added Lambda function + SAM template (`template.yaml`, `lambda/handler.py`) for S3 read operations (configs, profiles, bundles) via API Gateway — protects AWS credentials from client. Frontend dual base URL (`baseurl` for writes, `readUrl` for reads). Removed legacy S3 queue system (`process_scad_loop`, `queue()`, `.mod` files), `serve_download`, `downloads/` prefix, and individual STL upload code. Saved configs table now has Load/Download/Remove columns. Render status indicator shown during save with Save button disabled.
- **2026-03** – Replaced `stl_viewer.min.js` (StlViewer v1.08 / Three.js r86) with `web/stl_viewer.js`: thin wrapper over Three.js r160 (last UMD build) + STLLoader r170 + OrbitControls r170 (adapted to global scripts). Vendored under `web/vendor/three/`. Transform semantics (centering, world-axis rotation) preserved exactly. `get_model_info` returns `{ pos: [x,y,z] }` array for `inspect_ui.py` compatibility.
- **2026-03** – Fixed viewer assembly: `_preview_position_offsets` set to assembled bbox centers from v5.1 STLs; removed legacy 35° Z from tip/tipcover `_preview_rotate_offsets`. Created `docs/VIEWER_ASSEMBLY.md` documenting stl_viewer behaviour, coordinate system, and OpenSCAD ARM64 workaround. Added `.cursor/rules/fix-preview-positions.mdc`.
- **2026-03** – Four plug instances in preview: one plug STL shown four times (plug_0..plug_3) with per-instance position/rotation so plugs appear in tip holes; linkage preview position override so it displays behind the finger/socket. `/api/parts` expands plug and returns `stl_part` for URL lookup; frontend iterates part list and uses `stl_part` when resolving STL URLs.
- **2026-03** – Preview rotate offsets and preview config: STLs stay print-oriented; viewer applies preview_rotate_offsets, preview_position, and explode_offset from `/api/parts` so preview looks like an assembled finger and explode works without duplicating STLs. Stand hidden in preview by default. Cursor rule to keep docs updated.
- **2026-03** – Initial product/design doc; viewer error surfacing; parameter descriptions; part visibility checkboxes; Standard/Advanced layout; PRD + design decisions captured.

---

## Related documentation

- [Architecture](ARCHITECTURE.md) — system pipeline, class hierarchy, build flow, server, frontend
- [Parts Anatomy](PARTS_ANATOMY.md) — physical design of each part, mechanical connections, materials, known TODOs
- [CSG Patterns](CSG_PATTERNS.md) — SolidPython2 idioms, custom primitives, modeling patterns
- [Parameters](PARAMETERS.md) — parameter definitions, preview vs print orientation
- [Viewer Assembly](VIEWER_ASSEMBLY.md) — how the web viewer positions and rotates parts

## Cursor rules index

| Rule | Scope | Purpose |
|---|---|---|
| `parametric-consistency.mdc` | `finger_params.py`, `finger.py`, `finger_base.py` | Cascade checking, fewer-params principle |
| `csg-modeling-guide.mdc` | `finger.py`, `finger_base.py` | Primitive reference, geometry rules |
| `part-physical-context.mdc` | `finger.py` | Read physical context before modifying geometry |
| `coordinate-systems.mdc` | `finger_params.py`, `finger.py`, `viewer.js`, `stl_viewer.js` | Three coordinate spaces |
| `prop-system.mdc` | `Params.py`, `finger_params.py` | How the Prop descriptor works |
| `fix-preview-positions.mdc` | `finger_params.py`, `server.py`, `index.html` | Empirical fix for viewer preview positions |
| `web-ui-inspection.mdc` | `web/**`, `finger_params.py`, `scripts/*` | Never trust a running server; screenshot verification |
| `scad-preview.mdc` | `finger.py`, `server.py`, `scripts/*` | SCAD preview PNG verification |
| `geometry-validation.mdc` | `finger.py`, `finger_base.py`, `finger_params.py` | Topology checks, `_fn` visibility rule, post-CSG-rewrite checklist |
| `python-to-scad-translation.mdc` | `*.scad` | Transform order, formula, and OpenSCAD constraint pitfalls |
| `testing-and-make.mdc` | `scripts/*`, `Makefile`, `tests/**` | Use project make targets |
| `keep-docs-updated.mdc` | `danger/**`, `web/**`, `scripts/*`, `Makefile` | Keep docs updated on changes |
| `project-routing-map.mdc` | Always | Task-domain routing map — which docs to read for which task |
| `endpoint-state-map.mdc` | Always | Endpoint auth requirements, state locations, multi-instance implications |
| `archive-execution-plans.mdc` | Always | Archive plans to `.cursor/plans/` |

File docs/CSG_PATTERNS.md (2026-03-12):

# CSG Modeling Patterns

This document describes the SolidPython2 idioms and custom primitives used throughout the danger-finger codebase. Read this before modifying geometry code in `finger.py` or `finger_base.py`.

---

## SolidPython2 basics

The project uses [SolidPython2](https://github.com/jeff-dh/SolidPython2), which generates OpenSCAD code from Python. CSG operations:

| Python | OpenSCAD | Meaning |
|---|---|---|
| `a + b` | `union()` | Combine volumes |
| `a - b` | `difference()` | Subtract b from a |
| `a * b` | `intersection()` | Keep only overlap |
| `hull()(a, b)` | `hull()` | Convex hull of a and b |
| `a.rotate((rx, ry, rz))` | `rotate()` | Euler rotation (degrees) |
| `a.translate((x, y, z))` | `translate()` | Move |
| `a.scaleX(f)` / `.resize(...)` | `scale()`/`resize()` | Scale |
| `scad_render(obj)` | — | Generate .scad string |
| `obj.render()` | `render()` | Force evaluation (CSG cache) |

SolidPython2 builds a lazy tree. `.render()` evaluates it, which is important for complex boolean operations (avoids re-computation). The `build()` loop calls `.render()` on each model.

---

## Custom primitives (defined in `finger_base.py`)

### `rcylinder(r, h, rnd=0, center=False)`

Rounded-edge cylinder. Uses `rotate_extrude(offset(r=rnd)(offset(delta=-rnd)(square)))` to create filleted edges.

- `rnd=0`: Falls back to plain `cylinder()`
- Used extensively for hinges, struts, bumpers

### `rcube(size, rnd=0, center=True)`

Rounded-edge cube (4 edges rounded). Intersects a cube with a resized cylinder.

- `round_ratio = (1-rnd) * 1.1 + 0.5` controls how much the cylinder crops
- Used for struts, braces

### `rcubecyl(h, w, l, t, rnd=None, rnd1=None, rnd2=None, center=True)`

Hybrid cuboid-cylinder. The most complex primitive. Creates a rounded shape by hulling two scaled copies of a cylinder:

```python
anchor1 = cy.scaleX(.5).translateX(t / 2.0)
anchor2 = cy.scaleX(.5).translateX(-t / 2.0)
hub = hull()(anchor1, anchor2, cy)
return hub.rotate((90, 0, 0))
```

- `h`: height (cylinder axis), `w`: width (cylinder radius), `l`: length (resize X), `t`: hull offset
- `rnd1`/`rnd2`: Per-side rounding (left half / right half). Allows one end to be round and the other flat.
- Used for bridges and bumper shells

### `trim(x=0, y=0, z=0, center=True, offset=(0,0,0))`

Returns a transform function that intersects the object with a cutting cube. Axes set to 0 get a very large value (10000) so they don't clip.

```python
trim(x=10)(obj)            # functional style
obj.trim((10, 0, 20))      # method style (monkey-patched onto OpenSCADObject)
obj.trim((10, 0, 20), offset=(5, 0, 0))  # offset the cutting cube
```

### `flaredcyl(r, h, fr, fh)`

Flared cylinder using double-offset `rotate_extrude`. Creates a cylinder that widens at one end. Used for hinge inset flares.

### `circular_text(txt, radius, size, thickness, spacing, rot, reverse=False)`

Wraps text around a circle. Each character is positioned at an angle computed from character width heuristics (`WIDTH_ADJUSTMENTS` in `constants.py`). Used on the display stand.

---

## Key modeling patterns

### Hull pair pattern

The most common pattern. Two primitives are hulled together to create a smooth transition:

```python
mod_main = (mod_core + mod_hinge).hull() + (mod_tunnel + mod_core).hull()
```

This creates the base's body by hulling the core cylinder with the hinge, then hulling the tunnel with the core. The `+` combines both hulls into the final shape.

**Why**: Hulling two offset shapes creates a smooth, convex transition that is structurally strong and easy to print. Direct union of complex shapes often leaves internal voids or sharp transitions.

### Subtractive modeling

Most parts follow: build up material, then cut away features.

```python
final = (mod_main + mod_interface
         - mod_plug_cut      # subtract plug holes
         - mod_tip_hole       # subtract peg hole
         - mod_hinge_cut      # subtract hinge clearance
         - mod_pin            # subtract pin hole
         - cut[1].translate(...)  # subtract bridge cut
        ) - mod_extra + mod_washers - mod_pin
```

The order matters: additions first, then subtractions. Some features (like washers) are added after initial subtractions because they need to sit in the clearance zone.

### Orient dispatch pattern

Many methods take an `orient` parameter (an `Orient` IntFlag) and branch on it:

```python
if orient == Orient.PROXIMAL:
    trim_dim = self.intermediate_proximal_height
    trim_z = self.knuckle_width_[Orient.PROXIMAL] - self.knuckle_rounding * 4
else:  # DISTAL
    trim_dim = self.intermediate_distal_height
    trim_z = self.intermediate_width_[Orient.DISTAL]
```

The `orient_pair()` helper creates `{Orient.DISTAL: val, Orient.PROXIMAL: val}` dicts for computed properties that differ by orientation.

`Orient` is an `IntFlag`, so values can be combined: `Orient.PROXIMAL | Orient.OUTER` means "the proximal, outer portion" — used heavily in `bridge()` and `bridge_anchor()`.

### Computed property convention

Properties ending with `_` are computed (read-only):

```python
intermediate_width_ = property(lambda self: orient_pair(
    self.intermediate_distal_width_, self.intermediate_proximal_width_))
tip_radius = property(lambda self: self.tip_circumference / math.pi / 2)
```

These derive from user-facing `Prop` parameters. Never set them directly.

### Color coding

Each `part_*` method applies a `.color(PART_COLORS[name])` at the end:

```python
return final.color(PART_COLORS["base"])
```

`PART_COLORS` maps part names to `[r, g, b]` arrays (0-1 range) used by both OpenSCAD's `color()` command and the web viewer's material colors.

### Debug pattern

During development, `.debug()` (renders as `#` in OpenSCAD = transparent highlight) can be chained on any object:

```python
mod_hinge_cut.debug()  # show this subtraction as transparent
```

Many lines have `#.debug()` comments — these are inactive debug calls that can be re-enabled.

---

## Bridge and tunnel construction

The bridge/tunnel system is the most complex geometry in the codebase. It routes the tendon through the hinge zones.

### `bridge(length, orient, tunnel_width)`

Builds a tendon tunnel for external hinges (base and tip). Uses `bridge_anchor()` to create 8 anchor points (4 positions x 2 sides), hulls them, then subtracts a cylindrical channel.

The orient is composite: `Orient.PROXIMAL | Orient.OUTER` means "proximal end, outer part (base or tip side)".

### `bridge_anchor(orient, length, top, inside, shift, rnd)`

Calculates one anchor point for the bridge hull. Returns a small cylinder or sphere positioned at the correct height, width, and depth for the given orientation. The `shift` parameter mirrors the point across Z (left vs right side).

This method contains the most orientation-dependent branching in the codebase — it handles 8 combinations of orient, top/bottom, inside/outside, and distal/proximal.

### `make_bridge(orient, ...)`

A newer, simpler bridge method using `rcubecyl`. Used by base, tip, and middle (COVER/FULL bumper). Creates a single rounded cuboid, scales it, trims it, and subtracts a cylinder channel.

### `create_bridge(r, length, width, height, ...)`

Middle-section tunnel. Similar to `bridge()` but with different anchor geometry. Has a `sharp=True` mode for simpler variants.

---

## Monkey-patching

`finger_base.py` patches `OpenSCADObject` to add method-style `.trim()`:

```python
from solid2.core.object_base.object_base_impl import OpenSCADObject
OpenSCADObject.trim = _open_scad_trim
```

This allows `obj.trim((x, y, z))` instead of `trim(x, y, z)(obj)`.

---

## Common pitfalls

1. **Modifying a primitive affects all callers**: `rcylinder`, `rcubecyl`, `trim`, etc. are used throughout. Changes to these functions will affect every part.

2. **Hull order doesn't matter, but addition/subtraction order does**: `hull()(a, b)` is the same as `hull()(b, a)`, but `(a + b) - c` is different from `(a - c) + b`.

3. **`.debug()` in production**: Leaving `.debug()` active in a `build()` call makes the part transparent in OpenSCAD previews. The `.debug()` calls are commented out but easy to accidentally uncomment.

4. **`.render()` placement**: Calling `.render()` too early freezes the CSG tree, preventing further boolean operations. The `build()` loop calls it at the right time. Don't add extra `.render()` calls inside `part_*` methods.

5. **Scale vs resize**: `.scaleX(f)` multiplies by factor f. `.resizeX(dim)` sets absolute dimension. `.resize(0, 0, z)` only resizes Z — 0 means "keep original".

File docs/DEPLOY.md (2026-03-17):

# AWS Deployment Guide

## Architecture

```
                              ┌──────────────────────────────┐
┌──────────────┐  HTML/JS/CSS │ S3 static site (always on)   │
│   Browser    │◀────────────▶│ danger-finger-static          │
│              │              └──────────────────────────────┘
│              │
│              │  render POST  ┌──────────────────┐       ┌─────────────┐
│              │──────────────▶│ EC2 (t3a.medium)  │──────▶│ S3 (writes) │
│              │  (can fail)   │ Docker + OpenSCAD  │       │             │
│              │               │ Tornado :8081      │       │             │
└──────────────┘               └──────────────────┘       └──────┬──────┘
       │                                                          │
       │  configs/profiles  ┌─────────────────────┐               │
       └───────────────────▶│ API Gateway (HTTP)  │──▶ Lambda ───▶│ (reads)
                            └─────────────────────┘               │
                                                                  │
          ┌──────────────┐                                        │
          │ ECR (images) │◀── Docker push ────────────────────────┘
          └──────────────┘
```

- **S3 static site (`danger-finger-static`)**: Always-on frontend. Serves HTML, JS, CSS, and baked-in JSON for parts/params. If EC2 is down, the UI still loads and all read features work.
- **EC2**: Runs the Docker container with Tornado web server + OpenSCAD renderer. Handles render API calls (POST /api/preview, /api/render) and writes to S3.
- **Lambda + API Gateway**: Read-only serverless API for fetching configs, profiles, and bundle.zip from S3. Always available.
- **S3 (`danger-finger`)**: Persistent storage for all project data (configs, profiles, rendered bundles).
- **ECR**: Docker image registry. Lifecycle policy keeps last 10 images.
- **Route53 + ACM**: Optional custom domain and HTTPS (not enabled by default).

### Static site URLs

| Endpoint | URL | Use |
|---|-----|-----|
| CloudFront (HTTPS) | `https://d1n87lopz9qnnf.cloudfront.net` | Primary — use this for `DANGERFINGER_APP_URL` in WordPress wp-config.php. Required to avoid mixed-content blocking inside the HTTPS WP page. |
| S3 website (HTTP) | `http://danger-finger-static.s3-website-us-east-1.amazonaws.com` | Direct / debugging only |

The static site is the primary frontend. It loads without EC2. Preview/render calls go to EC2 and degrade gracefully with a "server offline" message when EC2 is down.

## Prerequisites

- AWS CLI v2 configured (`aws configure`)
- Docker Desktop running
- Terraform 1.5+ (`brew install terraform`)
- Python 3.12+ with boto3 (`pip install boto3`)
- Make

## Quick Start

```bash
# First time: initialize Terraform
cd infra && terraform init && cd ..

# Full deploy: build → push to ECR → apply infra → verify
make deploy

# Verify deployment
make verify-aws
```

## Makefile Targets

| Target | Description |
|---|---|
| `make ecr-login` | Authenticate Docker to ECR |
| `make push-ecr` | Build, tag, and push Docker image to ECR |
| `make deploy-infra` | Terraform plan + apply |
| `make deploy-ec2` | Update container on EC2 (SSM) |
| `make deploy-lambda` | Update Lambda function code |
| `make deploy` | Full pipeline: build → push → infra |
| `make verify-aws` | Post-deploy smoke tests |
| `make check-health` | Hit the render server health endpoint directly |
| `make check-monitoring` | Show current CloudWatch alarm states |
| `make audit-aws` | Full account audit |
| `make benchmark-ec2` | Run EC2 instance benchmark |

## Terraform Structure

```
infra/
  main.tf           — Provider, S3 backend
  variables.tf      — Input variables
  outputs.tf        — EC2 IP, API Gateway URL, etc.
  vpc.tf            — Default VPC, security groups
  ecr.tf            — ECR repository + lifecycle
  ec2.tf            — EC2 instance, IAM role, user data
  s3.tf             — S3 bucket config (versioning, access block)
  lambda.tf         — Lambda + API Gateway HTTP API
  dns.tf            — Route53, ACM (conditional)
  github_oidc.tf    — GitHub Actions OIDC (conditional)
  user_data.sh      — EC2 bootstrap script template
  environments/
    dev.tfvars      — Dev environment overrides
    prod.tfvars     — Prod environment overrides
```

## Environment Variables

### EC2 Container

| Variable | Description |
|---|---|
| `S3_BUCKET` | S3 bucket name (default: `danger-finger`) |
| `AWS_DEFAULT_REGION` | AWS region (default: `us-east-1`) |
| `READ_URL` | API Gateway URL for Lambda read API |

### Lambda

| Variable | Description |
|---|---|
| `S3_BUCKET` | S3 bucket name |

### Monitoring / Terraform

| Variable | Description |
|---|---|
| `alert_email` | Email address subscribed to SNS monitoring alerts (optional) |

## IAM

- **EC2**: Uses an IAM instance profile with ECR pull + S3 read/write. No static keys needed.
- **Lambda**: Execution role with S3 read-only (GetObject, HeadObject).
- **GitHub Actions**: OIDC federation — no static keys in CI. Set `github_repo` in tfvars to enable.

## Cost Estimate

| Resource | Monthly cost |
|---|---|
| EC2 t3a.medium (24/7) | ~$27 |
| S3 data bucket (minimal usage) | <$1 |
| S3 static site bucket | <$0.01 |
| Lambda (low volume) | <$1 |
| API Gateway | <$1 |
| Route53 zone (if enabled) | $0.50 |
| **Total** | **~$30** |

## Static Site Deployment

The frontend is served from S3 static website hosting. This provides always-on availability independent of EC2.

```bash
# Generate static JSON + deploy to S3
make deploy-static

# Specify custom URLs (otherwise reads from Terraform outputs)
make deploy-static READ_URL=https://YOUR_API_GW.amazonaws.com RENDER_URL=http://EC2_IP:8081/
```

When EC2 is down, the static site still loads and all read features (configs, profiles, parameter controls) work via Lambda. Only preview/render shows "server offline".

## Benchmarking

Run `make benchmark-ec2` or `python3 scripts/benchmark_ec2.py` to test instance types:

```bash
# Test specific types
python3 scripts/benchmark_ec2.py --types t3a.medium,c6a.large --timeout 2400

# Dry run (print user data script)
python3 scripts/benchmark_ec2.py --dry-run
```

### Benchmark results (2026-03-12, amd64, `latest` image)

| Type | Full render | Single part | Pull | $/hr | $/render | Score |
|---|---|---|---|---|---|---|
| t3a.medium | 40s | 3s | 42s | $0.0376 | $0.00042 | 0.418 ✓ best |
| c6a.large | 20s | 1s | 18s | $0.0765 | $0.00043 | 0.425 |
| c7a.large | 15s | 1s | 14s | $0.1026 | $0.00043 | 0.427 |
| t3a.xlarge | 34s | 2s | 29s | $0.1504 | $0.00142 | 1.420 |

**Score** = `($/hr × full_render_s / 3600) × 1000` — lower is cheaper per render.

**Recommendation**: `t3a.medium` wins on cost-per-render (all renders <45s = well within CPU credit burst window). Single-part preview is 3s on t3a.medium vs 1s on compute-optimized — negligible user-facing difference. The compute-optimized instances (c6a/c7a) offer faster absolute render times if UX latency is priority.

Note: `max_concurrent_tasks=2` in `scad_parallel()` is the **CLI batch rendering default** and does not affect web preview latency — web previews render parts sequentially (one per request). On a t3a.medium, a single tip preview takes ~3s end-to-end.

## Troubleshooting

### EC2 container not starting
```bash
# Check user data execution log
aws ssm send-command --instance-ids INSTANCE_ID --document-name AWS-RunShellScript \
  --parameters 'commands=["cat /var/log/cloud-init-output.log | tail -50"]'
```

### Lambda returning errors
```bash
# Check CloudWatch logs
aws logs tail /aws/lambda/danger-finger-s3-read --since 1h
```

### Terraform state issues
```bash
# List state resources
cd infra && terraform state list

# Remove a resource from state (if manually deleted)
terraform state rm aws_instance.app
```

### Monitoring and auto-recovery

The monitoring stack has two layers:

1. **EC2 system recovery** — CloudWatch alarms on `StatusCheckFailed_System` trigger AWS auto-recovery and send an SNS alert.
2. **Application health check** — a scheduled Lambda hits `GET /api/parts` every 5 minutes. If the request fails twice in a row, CloudWatch alarms send an alert. On each failing invocation, the Lambda attempts `docker restart danger-finger` via SSM.

Setup notes:
- Set `alert_email` in your Terraform variables before applying if you want email alerts.
- After the first apply, AWS SNS sends a subscription-confirmation email. Alerts do not flow until you confirm it.
- The health-check Lambda is intentionally lightweight: it probes the app endpoint without triggering a render job.

Operator commands:

```bash
# Check app health directly
make check-health

# Inspect CloudWatch alarm states
make check-monitoring

# Read health-check Lambda logs
aws --region us-east-1 logs tail /aws/lambda/danger-finger-health-check --since 1h
```

Failure behavior:
- If the EC2 host fails AWS system checks, AWS attempts instance recovery automatically.
- If the instance is up but Tornado/container is unhealthy, the scheduled Lambda attempts a restart through SSM.
- If the app stays unhealthy across consecutive checks, CloudWatch triggers the SNS alert and manual intervention is needed.

### Guest access and render recovery

The configurator now supports anonymous preview and anonymous render submission. Profile saves still require login.

Operational details:
- Full renders are queued as durable job records under `jobs/{job_id}` and mirrored to `render/{cfghash}/status` for hash-based polling.
- Authenticated jobs are dispatched ahead of guest jobs; guests are also rate-limited.
- On restart, the Tornado server scans queued/running jobs and requeues interrupted work. Recovery is whole-job requeue only; it does not resume partial OpenSCAD output mid-file.
- Bundle existence at `render/{cfghash}/bundle.zip` is the final source of truth for completion and dedupe.

Verification notes:
- Verify guest access from the WordPress wrapper, not just the raw app URL.
- Verify that a guest save click redirects to login and restores the draft after JWT callback.
- If testing restart recovery, kill the Tornado process during a queued/running render, let watchdog restart it, then poll the job/status endpoint until it resumes or completes.

## CI/CD (GitHub Actions)

The `.github/workflows/deploy.yml` workflow:
1. **Test**: Build Docker image, run e2e tests
2. **Deploy**: Push to ECR, apply Terraform, update EC2 container
3. **Verify**: Run smoke tests against deployed environment

Requires:
- GitHub repository secret: `AWS_ACCOUNT_ID`
- OIDC: Set `github_repo` in Terraform to enable the IAM role

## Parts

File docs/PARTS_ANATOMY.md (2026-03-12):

# Parts Anatomy — Physical Design of the Danger Finger

This document describes each part of the prosthetic finger from a physical and mechanical perspective: what it does, how it connects to adjacent parts, what material it should be printed in, and which parameters most affect it. Read this before modifying any `part_*` method in `finger.py`.

---

## How the finger works

The Danger Finger is a body-powered prosthetic for people missing a finger at any phalange. The key mechanical principles:

1. **Socket** slides over the remnant finger stub (flexible material for comfort)
2. **Base** snaps into the socket via a ridged cylindrical interface
3. **Middle** connects to the base via a proximal hinge joint
4. **Tip** connects to the middle via a distal hinge joint
5. **Tipcover** (flexible) snaps onto the tip, providing a soft fingertip with fingerprint texture
6. **Linkage** runs from the base, under a bracelet on the wrist
7. **Tendon** (fishing line) threads through tunnels in all segments, attaching to the linkage
8. **Elastic cord** threads through the base, providing the return (extension) force

When the user bends their remnant finger, the base tilts forward in the socket, pulling the linkage. The linkage tension propagates through the tendon, curling the finger naturally at both hinge joints. When the remnant straightens, elastic restores the finger to its extended position.

```
                    ┌──tipcover (flexible, snaps on)
                    │
        ┌───tip─────┘    ← distal hinge (pin + plugs)
        │
    ┌───middle───┐       ← 3 struts + cross brace + bumper
    │            │
    └───base─────┘       ← proximal hinge (pin + plugs)
        │
        socket           ← slides over remnant (flexible)
        │
     ───linkage──→ bracelet on wrist
```

---

## Coordinate system (assembled, natural orientation)

In the natural/assembled coordinate system used by the CSG code:

- **Y axis**: finger length. Y=0 is the proximal hinge center. +Y toward tip, -Y toward hand.
- **X axis**: dorsal/palmar. +X is the dorsal (top/back) side of the finger.
- **Z axis**: lateral. +Z is one side, -Z the other.

`part_tip()` bakes `translate((0, intermediate_length, 0))` into its geometry, offsetting the tip by the middle segment length so it appears in the correct assembled position.

Print orientation rotates each part for optimal FDM printing (flat base, minimal supports). See `_rotate_offsets` in `finger_params.py`.

---

## Part-by-part anatomy

### Socket (`part_socket`)

**Material**: Flexible (TPU/NinjaFlex)
**Role**: Slides over the remnant finger stub; holds the base via friction-fit ridged interface.

**Key features**:
- **Tapered cylinder**: `socket_circumference_distal` (narrower, near base) to `socket_circumference_proximal` (wider, near hand). Wall thickness varies: `socket_thickness_distal`, `socket_thickness_middle`, `socket_thickness_proximal`.
- **Socket interface (outer)**: Cylindrical section at the top that mates with the base's inner interface. Has optional radial cuts (`socket_interface_cuts`) for flex grip.
- **Scallops**: Left and right side cutouts (`socket_scallop_depth_left/right`) that remove material for comfort and allow the socket to flex around the remnant. Controlled by `SCALLOP_HEIGHT` and `SCALLOP_RADIUS_ADJ`.
- **Bottom cut**: `socket_bottom_cut` removes material from the palm side of the socket (where the finger bends), controlled by `SOCKET_BOTTOM_CUT_FACTOR`.
- **Ridge rings**: Concentric ridges (`_socket_bottom` method) add grip texture inside the socket body.
- **Tendon cut**: Angled cut (`TENDON_CUT_ROTATE = -80`) near the top provides a channel for the tendon to exit toward the linkage.
- **Rotation for draft**: The socket is rotated 20 degrees during construction (`rotate((0,20,0))`) then un-rotated, creating a slight draft angle that improves insertability.

**Key parameters**: `socket_depth`, `socket_circumference_distal/proximal`, `socket_thickness_*`, `socket_bottom_cut`, `socket_scallop_depth_*`, `socket_interface_*`

**Interfaces with**: Base (via socket_interface cylinder)

---

### Base (`part_base`)

**Material**: Rigid (PLA/PETG)
**Role**: Proximal segment. Connects socket to middle via the proximal hinge. Routes tendon and elastic.

**Key features**:
- **Core**: A flanged cylinder (`_mod_core`) at the socket end that transitions into the hinge geometry.
- **Outer hinge** (`knuckle_outer`, Orient.PROXIMAL): Rounded cylinder with a pin hole, washer grooves, and a clearance cut for the mating inner hinge. The hinge tab width is `knuckle_proximal_thickness`; the overall width is `knuckle_proximal_width`.
- **Socket interface (inner)**: Ridged cylinder (`socket_interface`, Orient.INNER) that friction-fits into the socket's outer interface. Ridges (`socket_interface_ridges`) and optional flex cuts improve grip. `socket_interface_clearance` controls the fit tolerance.
- **Tendon routing**: `tendon_hole()` cuts two hulled tube channels through the base for the fishing line. The holes can be shifted upward by `knuckle_tendon_offset` to create a mechanical advantage (with a corresponding `_tendon_bulge` that adds material to accommodate the shifted hole).
- **Elastic routing**: `elastic_hole()` cuts four channels (two pairs) for the elastic return cord. They run from the base's socket end through to the hinge area.
- **Breather hole**: A cylinder cut through the body between the hinge and socket interface, allowing air escape during socket insertion.
- **Bridge/tunnel**: Tendon guide structures (`bridge()` + `make_bridge()`) that route the tendon smoothly through the hinge zone.
- **Front cut**: `_front_cut()` removes a small wedge from the front/bottom of the base for knuckle clearance during flexion.
- **Plug cuts**: Four plug socket holes (proximal left/right, distal left/right) for the hinge pin cover plugs.

**Key parameters**: `proximal_length`, `knuckle_proximal_width/thickness`, `socket_interface_*`, `knuckle_tendon_offset`, `tunnel_*`, `tendon_hole_radius/width`

**Interfaces with**: Socket (via socket_interface), Middle (via proximal hinge pin)

---

### Middle (`part_middle`)

**Material**: Rigid (PLA/PETG)
**Role**: Intermediate segment connecting base to tip. Transmits tendon force. Allows flexion at both hinges.

**Key features**:
- **Dual inner hinges** (`knuckle_inner`): One at each end (proximal and distal). Inner hinges are the "socket" side — they receive the outer hinge cylinders from the base and tip. Each has a flared inset (`knuckle_inset_border`, `knuckle_inset_depth`) that creates a channel for the tendon to pass through without binding.
- **Three struts**: Top-left, top-right, and bottom struts hull-connect the two hinges. The bottom strut is rotated by `intermediate_strut_rotate` to provide fist clearance (so the finger doesn't collide with the palm when fully curled).
- **Cross brace** (`cross_strut`): A transverse bar at the midpoint connecting the top struts for lateral rigidity. Height controlled by `knuckle_brace_height_factor`.
- **Bumper**: Optional protective shell around the middle section. `intermediate_bumper_style` selects NONE, MINIMAL, COVER, or FULL. The COVER style (`_create_cover_bumper`) wraps the struts in a thin shell via `rcubecyl` with a hollow interior. `intermediate_bumper_width` controls thickness.
- **Bridge tunnels**: When bumper style is not COVER/FULL, separate `create_bridge()` tunnels at each end guide the tendon. When COVER/FULL, the `make_bridge()` method creates integrated bridge structures.
- **Side trims**: Cylinder cuts at each end ensure the inner hinge doesn't interfere with the outer hinge's clearance zone.
- **Tendon channel**: When bumper is COVER/FULL, a tendon-shaped hull cut runs through the bumper for the fishing line.

**Key parameters**: `intermediate_length`, `intermediate_distal_height`, `intermediate_proximal_height`, `knuckle_distal/proximal_width`, `intermediate_bumper_style/width`, `knuckle_inset_*`, `intermediate_strut_rotate`, `strut_*`, `tunnel_*`

**Interfaces with**: Base (proximal hinge), Tip (distal hinge)

**Critical**: `intermediate_length` is the single most important parameter — it determines the finger's overall length and affects the Y-position of every part distal to the proximal hinge.

---

### Tip (`part_tip`)

**Material**: Rigid (PLA/PETG)
**Role**: Distal segment. Houses the peg hole for the tendon anchor. Receives the tipcover snap-fit.

**Key features**:
- **Outer hinge** (`knuckle_outer`, Orient.DISTAL): Same structure as the base hinge but at the distal end.
- **Tip core**: An `rcylinder` with `tip_radius` (derived from `tip_circumference/pi/2`) that forms the dome-shaped fingertip. This is the visual and structural terminus of the rigid finger.
- **Tip interface** (`tip_interface`): A post-and-ridge snap-fit system. A central post (`tip_interface_post_height`, `tip_interface_post_radius_`) with a circumferential ridge (`tip_interface_ridge_radius`, `tip_interface_ridge_height`) that the flexible tipcover snaps onto. The ridge has a chamfer for easier insertion.
- **Peg hole**: A tapered cylinder (`part_peg` subtracted from the tip) that serves as the tendon anchor point. The fishing line terminates here, secured by the peg. Four support cylinders (`PEG_SUPPORT_RADIUS`, `PEG_SUPPORT_TRANSLATE_Z`, `PEG_SUPPORT_SIDE_X_OFFSET`) reinforce the peg channel.
- **Bottom trim**: Removes material from the underside to improve fist clearance.
- **Fist trim**: An angled cube cut (`TIP_FIST_TRIM_ROTATE = -25`) that trims the palm side of the tip, preventing collision when the finger is fully curled.
- **Bridge/tunnel**: Same structure as the base, routing the tendon through the hinge zone.

**Key parameters**: `tip_circumference`, `distal_length`, `distal_base_length`, `knuckle_distal_width/thickness`, `tip_interface_*`, `distal_flange_height`

**Interfaces with**: Middle (distal hinge), Tipcover (snap-fit interface), Peg (tendon anchor)

**Note**: `part_tip()` applies `translate((0, intermediate_length, 0))` to the final geometry, placing it at the correct assembled position relative to the proximal hinge origin.

---

### Tipcover (`part_tipcover`)

**Material**: Flexible (TPU/NinjaFlex)
**Role**: Soft fingertip that snaps onto the tip. Provides grip, appearance, and protection.

**Key features**:
- **Shell**: A hull of a cylinder and sphere that creates the finger-shaped dome. `tipcover_thickness` controls wall thickness. The inner surface is hollowed by a slightly smaller version of the tip interface post.
- **Snap-fit interface**: The inner cavity has a matching ridge that clicks onto the tip's post, held by friction. `tip_interface_clearance` controls the gap.
- **Nail cut**: A sphere subtracted from the dorsal (top) side that creates a nail-like depression for aesthetics.
- **Fingerprints**: Concentric sphere intersections with alternating stripe cuts create a tactile fingerprint pattern. `tip_print_depth` controls ridge depth (negative inverts), `tip_print_width` controls stripe spacing, `tip_print_factor` controls sphere radius, `tip_print_offset` positions the pattern.

**Key parameters**: `tipcover_thickness`, `tip_circumference`, `tip_print_*`, `tip_interface_*`

**Interfaces with**: Tip (snap-fit)

---

### Linkage (`part_linkage`)

**Material**: Rigid (PLA/PETG)
**Role**: Connects the finger to a wrist bracelet. Transmits pull force from remnant finger flexion to tendon.

**Key features**:
- **Core bar**: An `rcylinder` resized to an oval cross-section (`linkage_width` x `linkage_height`), intersected with a cube for flat sides. Length is `linkage_length`.
- **Hook** (`link_hook`): A loop at one end that hooks onto the wrist bracelet's elastic band. Controlled by `linkage_hook_*` parameters (length, height, thickness, opening, offset, inset, rounding, end_inset).
- **Tendon hole**: A long cylinder bored through the center for the fishing line. `linkage_flat` adds width to the oval.
- **Cross holes**: `linkage_holes` evenly-spaced holes perpendicular to the tendon, connected by slits. These allow tension adjustment — the user can thread the tendon through different holes to change the effective pull distance.
- **Hull transition**: The hook and core are hull-connected for a smooth structural transition.

**Key parameters**: `linkage_length`, `linkage_width`, `linkage_height`, `linkage_hook_*`, `linkage_holes`, `linkage_hole_spacing`, `linkage_flat`

**Interfaces with**: Base (tendon runs through base tunnels to linkage), wrist bracelet (hook)

---

### Plug (`part_plug`)

**Material**: Rigid (PLA)
**Role**: Cap for the hinge pin hole. Prevents the pin from sliding out.

**Key features**:
- **Two-part cylinder**: A wider base with a ridge (`knuckle_plug_ridge`) that friction-fits into the hinge's pin hole. `knuckle_plug_radius` controls diameter; `knuckle_plug_thickness` controls depth.
- **Clearance version**: `part_plug(clearance=True)` adds `knuckle_plug_clearance` to create the mating hole in the hinge. `clearance=False` creates the actual plug.
- **Four instances**: `part_plugs()` creates four plugs at the correct positions: proximal left/right, distal left/right.

**Key parameters**: `knuckle_plug_radius`, `knuckle_plug_thickness`, `knuckle_plug_ridge`, `knuckle_plug_clearance`

**Interfaces with**: Base (2 plugs), Tip (2 plugs)

---

### Peg (`part_peg`)

**Material**: Rigid (PLA)
**Role**: Tendon anchor inserted into the tip's peg hole.

**Key features**:
- Tapered cylinder (`r1=tendon_hole_radius*2, r2=tendon_hole_radius*1.3`)
- Optionally hollow (`peg_hollow_radius`) for tying the tendon through it
- Oriented and positioned to align with the peg hole in `part_tip`

**Key parameters**: `tendon_hole_radius`, `peg_hollow_radius`, `distal_base_length`

**Interfaces with**: Tip (peg hole)

---

### Pins (`part_pins`)

**Material**: Rigid (PLA) or metal rod
**Role**: Hinge axles. One pin for proximal hinge, one for distal.

**Key features**:
- Simple cylinders at `knuckle_pin_radius` with length matching the hinge width minus plug thickness.
- Both pins are generated as a single composite STL (proximal at Y=0, distal at Y=10), which is why the web viewer skips pins (the composite cannot be correctly positioned with a single offset).

**Key parameters**: `knuckle_pin_radius`, `knuckle_proximal/distal_width`, `knuckle_plug_thickness`

**Interfaces with**: Base (proximal), Middle (both), Tip (distal), Plugs (cap the ends)

---

### Stand (`part_stand`)

**Material**: Rigid (PLA)
**Role**: Display stand for the assembled finger. Not a functional part.

**Key features**:
- Inner shape matches the socket's inner cavity (reuses `_socket_bottom_bit`), so the assembled finger sits snugly.
- Outer base is a wider rounded cylinder with "DangerFinger v5.1 2014-2026" circular text.
- `stand_depth_factor` controls how deep the stand is relative to `socket_depth`.

**Key parameters**: `stand_depth_factor`, `socket_depth`, `socket_radius_*`

**Interfaces with**: Socket (display only)

---

### Bumper (`part_bumper`)

**Material**: Flexible (TPU)
**Role**: Protective sleeve around the middle section. Separate from the bumper integrated into `part_middle` when `intermediate_bumper_style` is COVER/FULL.

**Key features**:
- A thin-walled `rcubecyl` shell that slides over the middle section's struts.
- Only generated when `intermediate_bumper_style` is not NONE.

**Key parameters**: `intermediate_bumper_width`, `intermediate_bumper_style`

**Interfaces with**: Middle (slides over)

---

## The hinge system in detail

Each hinge consists of an **outer** part (on base or tip) and an **inner** part (on middle). They interleave like a door hinge:

```
 Outer hinge (on base or tip)          Inner hinge (on middle)
 ┌──────────────────────────┐          ┌──────────────────────────┐
 │  ███░░░░░░░░░░░░░░░░███  │          │  ░░░██████████████████░░░│
 │  ███░░░░pin hole░░░░███  │          │  ░░░██████████████████░░░│
 │  ███░░░░░░░░░░░░░░░░███  │          │  ░░░██████████████████░░░│
 └──────────────────────────┘          └──────────────────────────┘
   ▲ plug                  plug ▲         ▲ inset gap           inset gap ▲
```

- **Outer** (`knuckle_outer`): Full-width rounded cylinder. Pin hole through center. Clearance cut removes a cylinder-shaped void for the inner hinge to nestle into. Washer grooves reduce friction.
- **Inner** (`knuckle_inner`): Narrower cylinder (width = `intermediate_width_[orient]`). Flanged inset (`knuckle_inset_border`, `knuckle_inset_depth`) creates tendon channels. Anchor points for struts are generated here.
- **Pin**: Simple cylinder through both, length = hinge width - 2 * plug thickness.
- **Plugs**: Cap the pin holes on each end.
- **Washers**: Built-in annular ridges on the outer hinge that reduce friction between the inner and outer hinge faces.

Critical clearances:
- `knuckle_clearance`: Gap between inner and outer hinge cylinders (radial)
- `knuckle_side_clearance`: Gap between inner hinge face and outer hinge wall (axial)
- `knuckle_plug_clearance`: Gap between plug and its hole

---

## The tendon/tunnel system

Fishing line runs from the linkage, through the base, through both hinge zones, through the middle, to the peg in the tip:

```
Linkage → tendon_hole (base) → bridge tunnel (proximal hinge zone)
  → create_bridge tunnels (middle proximal end)
  → [through middle body] →
  → create_bridge tunnels (middle distal end)
  → bridge tunnel (distal hinge zone) → peg hole (tip)
```

The tunnel system is built from `bridge()` and `bridge_anchor()` methods, which generate hull-connected anchor points at specific heights and widths. The tunnel interior is subtracted using `rcylinder` cuts.

Key tunnel parameters:
- `tunnel_height`: How far the tunnel extends above the hinge center
- `tunnel_radius`: Radius of the tunnel tube
- `tunnel_inner_height`: Extra height for the inner (middle) end
- `tunnel_inner_slant`, `tunnel_outer_slant`, `tunnel_outer_flare`: Control the tunnel's narrowing/widening as it transitions between segments
- `tunnel_inner_rounding`: Rounding on the inner tunnel edges

---

## The socket interface

The socket and base connect via a cylindrical friction-fit interface:

```
Socket (outer)                     Base (inner)
┌────────────────────────┐        ┌────────────────────────┐
│ ╔═══════════════════╗  │        │  ┌───────────────────┐ │
│ ║  ridges (outer)   ║  │  ←→   │  │ ridges (inner)    │ │
│ ║  socket_iface_rad ║  │        │  │ socket_iface_rad  │ │
│ ║  + thickness      ║  │        │  │ - clearance       │ │
│ ╚═══════════════════╝  │        │  └───────────────────┘ │
└────────────────────────┘        └────────────────────────┘
```

- `socket_interface_radius_distal/proximal`: Radius at each end (tapered)
- `socket_interface_thickness`: Wall thickness of the interface cylinder
- `socket_interface_clearance`: Gap between base (inner) and socket (outer) — negative for interference fit
- `socket_interface_ridges`: Number of vertical ridges for grip (0 disables)
- `socket_interface_ridge_width`, `_inner`, `_outer`: Ridge geometry
- `socket_interface_cuts`: Whether radial flex cuts are present (helps the interface flex for insertion)

The `socket_interface()` method generates both the inner (for base, with clearance subtracted) and outer (for socket, at full size) versions based on the `orient` parameter.

---

## Known modeling challenges and TODOs

These are extracted from code comments and represent the key areas where future parametric work is needed:

### Tier 1 — Hardcoded values that should be derived
- `ANCHOR_OFFSET_DISTAL = -0.485` — should derive from `strut_height_ratio` and `knuckle_clearance`
- `SCALLOP_HEIGHT = 9` — may be derivable from `socket_bottom_cut`
- `PEG_SUPPORT_*` constants — should derive from `tendon_hole_radius` and `distal_base_length`
- `TIP_CORE_RESIZE_INSET = 2` — should be proportional to `tip_radius`
- `breather_radius_factor`, `breather_height`, `breather_translate_y` — should derive from base dimensions

### Tier 2 — Features that need parameterization
- Cross strut width (currently hardcoded in `cross_strut`)
- Bridge height (hardcoded; TODO comments say "make configurable")
- Socket texture / cuts (separate from interface ridges)
- Fist clearance geometry (multiple HACK comments)
- Bumper parametrics (COVER style has several hardcoded dimensions)

### Tier 3 — Structural improvements
- Snap knuckles instead of pins (mentioned in TODO at top of finger.py)
- Width resize for tip and base (TODO 3 in multiple places)
- Better fist bottom cut for tipcover
- Separate socket cut config vs base cut config
- Plug rotation for left vs right hand

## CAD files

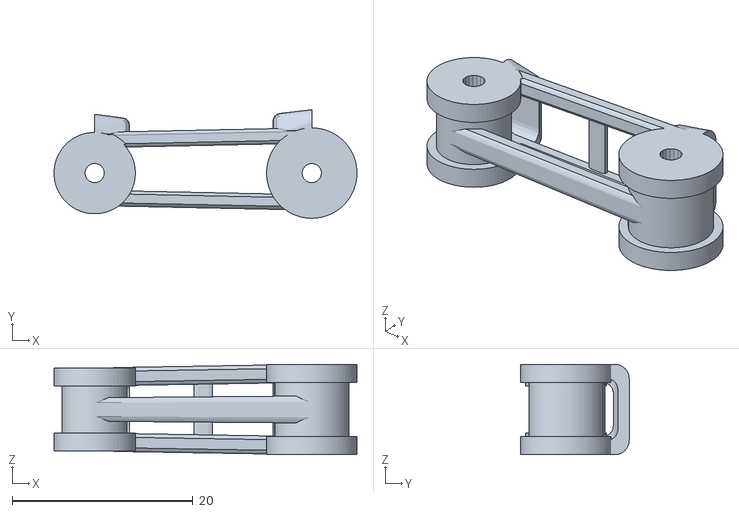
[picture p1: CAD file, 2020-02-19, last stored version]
output/dangerfinger_v4.2_middle.stl
33.5 x 12.0 x 10.00

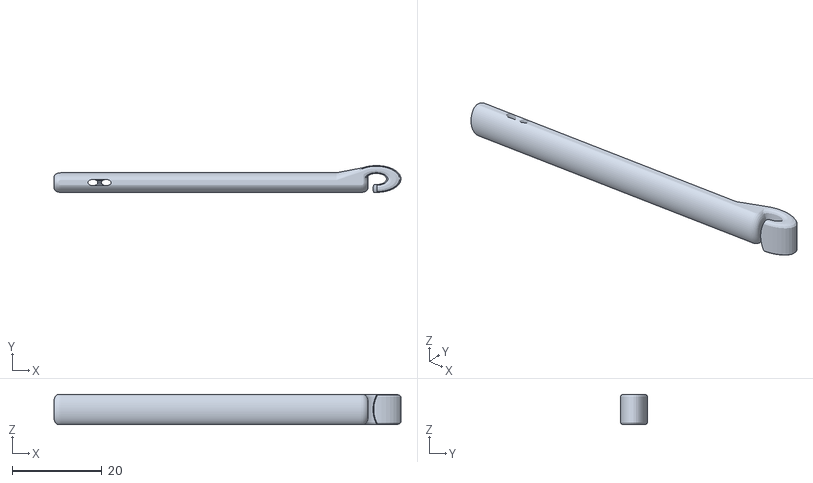
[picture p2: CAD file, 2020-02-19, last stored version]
output/dangerfinger_v4.2_linkage.stl
77.4 x 6.00 x 6.80

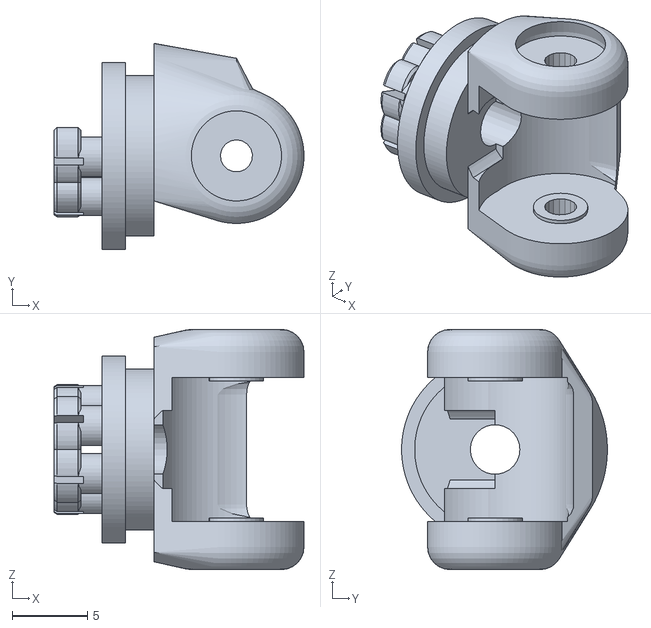
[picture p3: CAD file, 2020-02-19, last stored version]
output/dangerfinger_v4.2_tip.stl
16.6 x 13.7 x 16.0

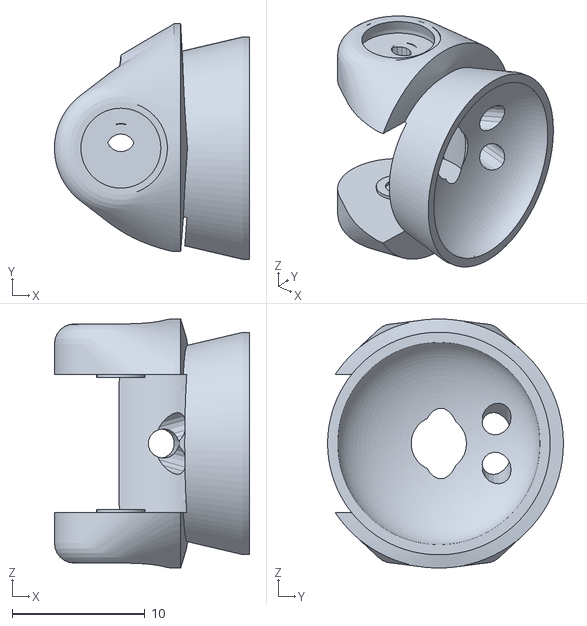
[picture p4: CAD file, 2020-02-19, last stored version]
output/dangerfinger_v4.2_base.stl
14.7 x 17.7 x 18.7

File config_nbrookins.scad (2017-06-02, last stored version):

//part = 3;
//cutaway = 0;

echo ("\n..........................................................\n");
echo ("\nDangerFinger: Nick Brookins");
echo ("\n..........................................................\n");
	
/* [Socket Fit Settings] */
//Very important for fit!  Diameter of the top of socket, roughly the diameter/width of the finger stump nearer the end.  You may want to print multiple sockets with different thciknesses, as this can vary depending on healing, and swelling, even throughout a single day.  
socket_circumference_distal = 51; //52.5
//SK; 50, 48, 52

//diameter of the bottom of socket, roughly the diameter/width of the finger stump bottom.  This and the other diameter can be the same, but I have better luck making the socket tighter at the top, for a firmer hold.
socket_circumference_proximal = 66;// 68 =>21.65
//SK: 17.5; 55, 55, 61

//Depth of the socket, roughly equates to the length of the finger stump to the start of the next knuckle  
socket_depth_top = 34;
//NB: 36
//SK: 31
socket_depth = socket_depth_top;
//Depth of the socket near the palm, typically shorter to account for flexing to a fist.  Should be smaller than socket_depth_top
socket_depth_bottom = 24.5;
//NB: 25
//SK: 23

//Deptch of the scallopped cutout on each side, to make room for webbing for the next finger.  Should be smaller than socket_depth_bottom.
socket_depth_scallop_left = 20;
socket_depth_scallop_right = 24;

/* [Finger Length Settings] */

//length of the overall tip section, including the tip cover, from hinge pin, to end.  Should be set to length of finger tip from mid-knuckle to end.
tip_length = 24.5;
//24.5

//length of the middle part, from pin to pin.  Should be roughly same as length from mid-first knuckle, to mid-second knuckle.
middle_section_length = 31;
//NB: 31
//additional height of the base section, which connects to the socket and has the first hinge.  Keep this low in order to have the base hinge as close to the finger remnant as possible.  Increase it if the knuckle needs to be extended in order to align with other fingers.

base_extra_length = .5;

//length of the back-of-hand linkage.  Some matter of preference, this should be less than the length of back-of-hand, from knuckles to wrist.  It also depends on how tight the bracelet it links to is around the wrist.
linkage_length = 62;

/* [Other adjustments] */
//Which form of sides to use for the middle section.  0 to print attached plastic bumpers, or 1 for seperate (rubber) bumpers
middle_sides = 1 ;//[0:Built-in sides, 1:Slots for rubber bumper]

//a split to make it easyier to get less-elastic bumper over the middle part.  negative for split on one side, positive for the other.
bumper_split = -.1;//[.1:Left Split, -.1:Right Split, 0:Solid Bumper]

//thickness of the rubber, for socket near top.  Again preference, thinner will be more flexible and streamlined, but with less strength and stability.
socket_thickness_top = 1.9;
socket_thickness_mid = 1.65;
//thickness of the rubber socket near bottom.  I like this to be thinner - allowing for more strength where the socket interfaces with the base, while having less bulk near my hand.
socket_thickness_bottom = 1.4;

//amount to taper the opening of socket for comfort
socket_taper = .7; 

//width of the scallops as ratio of socket width 
socket_width_scallop = .75;

//Advanced: diameter of middle section,  have'nt yet tested different values here.  minimum of 15 for tunnels to fit.
middle_diameter = 15; //15
//TODO: 15

//Advanced: width of middle segment (not counting bumper), generally the width between the hinges.  Be careful with this one.
middle_width = 8; 
//TODO: 8.5

//Advanced: width at the base of the rubber tip cover, compared to middle section.  typically negative.
tip_width = -1.5;  
//TODO: -1.5

//Advanced: the percentage of the tip cover length which the fingernail covers
tip_fingernail_ratio = .47;
//TODO: .43

//Advanced: width of the linkage
linkage_width = 7;
//TODO: 8

//Diameter of the clearance hole around the hinge pin nuts
hinge_pin_clearance = 6;
//TODO: 6.75

//Advanced: hinge inner diameter
hinge_diameter = 9;

socket_interface_length=4.25;

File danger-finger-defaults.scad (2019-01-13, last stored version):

// Knick's finger v3.71
// Copyright 2014-2016 Nicholas Brookins and Danger Creations, LLC
// http://dangercreations.com/prosthetics
// http://www.thingiverse.com/thing:1340624
//
// Released under Creative Commons Attribution-NonCommercial-ShareAlike 4.0  https://creativecommons.org/licenses/by-nc-sa/4.0/
// Source code licensed under Apache 2.0: https://www.apache.org/licenses/LICENSE-2.0

/* [Socket Fit Settings] */
//Very important for fit!  Diameter of the top of socket, roughly the diameter/width of the finger stump nearer the end.  You may want to print multiple sockets with different thciknesses, as this can vary depending on healing, and swelling, even throughout a single day.
socket_circumference_distal = 54.0;
//NB 52 ->

//diameter of the bottom of socket, roughly the diameter/width of the finger stump bottom.  This and the other diameter can be the same, but I have better luck making the socket tighter at the top, for a firmer hold.
socket_circumference_proximal = 65.0;
//NB 61 ->

//Depth of the socket, roughly equates to the length of the finger stump to the start of the next knuckle
socket_depth_top = 36;

socket_depth = socket_depth_top;
//Depth of the socket near the palm, typically shorter to account for flexing to a fist.  Should be smaller than socket_depth_top
socket_depth_bottom = 27;

//Deptch of the scallopped cutout on each side, to make room for webbing for the next finger.  Should be smaller than socket_depth_bottom.
socket_depth_scallop_left = 22;
socket_depth_scallop_right = 26;

/* [Finger Length Settings] */
//length of the overall tip section, including the tip cover, from hinge pin, to end.  Should be set to length of finger tip from mid-knuckle to end.
tip_length = 25.5;

//length of the middle part, from pin to pin.  Should be roughly same as length from mid-first knuckle, to mid-second knuckle.
middle_section_length = 32;

//additional height of the base section, which connects to the socket and has the first hinge.  Keep this low in order to have the base hinge as close to the finger remnant as possible.  Increase it if the knuckle needs to be extended in order to align with other fingers.
base_extra_length = -0.75;
base_tendon_offset = -0.25;
//optional breather hole in base
base_breather_diameter = 3.75;

 //Advanced: diameter of middle section,  have'nt yet tested different values here.  minimum of 15 for tunnels to fit.
middle_diameter = 13.50; //15

//length of the back-of-hand linkage.  Some matter of preference, this should be less than the length of back-of-hand, from knuckles to wrist.  It also depends on how tight the bracelet it links to is around the wrist.
linkage_length = 70;

/* [Other adjustments] */
//Which form of sides to use for the middle section.  0 to print attached plastic bumpers, or 1 for seperate (rubber) bumpers
middle_sides = 1 ;//[0:Built-in sides, 1:Slots for rubber bumper]

//thickness of the rubber, for socket near top.  Again preference, thinner will be more flexible and streamlined, but with less strength and stability.
socket_thickness_top = 2.0;
socket_thickness_mid = 1.8;
//thickness of the rubber socket near bottom.  I like this to be thinner - allowing for more strength where the socket interfaces with the base, while having less bulk near my hand.
socket_thickness_bottom = 1.4;

socket_ridge_depth = 0.2;
socket_ridge_spacing = 0.6;

//amount to taper the opening of socket for comfort
socket_taper = .7;

//width of the scallops as ratio of socket width
socket_width_scallop = .75;

/* [Advanced Clearances] */
//Advanced: clearance between hinge and middle section on sides
hinge_side_clearance = .35;

//Advanced: extra clearance for the hinge plugs, or negative to make them slightly bigger for a pressure fit
hinge_plug_clearance = 0.1;
//Advanced: radius of the hinge pin/axle .  On my printer R 1.06 works perfect for a 2mm diameter shaft.
hinge_pin_radius = 1.08;

//Advanced: radius of the elastic and tendon tunnels
tunnel_radius = 1.1;

//Advanced: radius of set screws on tensioner block.  set to 0 to disable tensioner
tip_tensioner_screw_radius = .94;

//radius of set screws on base.  set to 0 to disable tensioner
base_tensioner_screw_radius = 0;
base_tensioner_flare = 1.5;

//cut a hole into the side of the linkage, great for a set screw
linkage_angle_hole_radius = 0;

//radius of the tendon string hole
linkage_hole_radius = 1.25; //1.44;

//Clearance between socket and base.  -.5 for Ninja flex and sloopy printing to +.5 for firm tpu and accurate
socket_clearance = -0.25;
socket_vertical_clearance = .1;

socket_interface_length=5;

/* [Other Advanced] */
//Advanced: hinge inner diameter
hinge_diameter = 8.2;

//Diameter of the clearance hole around the hinge pin nuts
hinge_plug_diameter = 6.5;
//TODO: 6.75
//Advanced: thickness of the hinge plugs
hinge_plug_thickness = 1.1;
//TODO: 1.8

//Advanced: radius of an accessory hole from the tip cover end, great for LEDs and lasers :)
tip_accessory_radius = 0;

//Advanced: width of middle segment (not counting bumper), generally the width between the hinges.  Be careful with this one.
middle_width = 8.0;

//Advanced: width at the base of the rubber tip cover, compared to middle section.  typically negative.
tip_width = -4.0;

//Advanced: the percentage of the tip cover length which the fingernail covers
tip_fingernail_ratio = .48;
//TODO: .43

//Advanced: width of the linkage
linkage_width = 6.75;
//TODO: 8
slot_len = 9.0;
slot_spacing = 2.65;
slot_width = linkage_width*.18;

//Advanced: height of the linkage
linkage_height = 4.25;
//advanced, height of the hook
linkage_end2_height = 6.8;
//advanced, length of the hook
linkage_end2_length = 12.25;

//offset from end 1
linkage_angle_hole_offset = 4.5;

/* [Hidden] */

//advanced, length of the hole
linkage_hole_length = linkage_length*0.8;//20;
//advanced, radius of a hole through the entire linkage
linkage_holethrough_radius = 0;//.75;

//optional angle modifier
linkage_angle_hole_angle = 15;
//how much rounding to apply to end 1
linkage_end1_round = 1.2;
//how much rounding to apply to end 2
linkage_end2_round = 1.2;

//advanced, width of the hook
linkage_end2_width = 5.5;
//advanced, thickness of the hook
linkage_end2_thickness = 2.3;
//advanced, offset of the hook
linkage_end2_offset = -0.2;

//which end style to use for end1
linkage_end1 = 2; //[0:Plain,1:Hole,3:Loop, 5:Hook ]
//which end style to use for end2
linkage_end2 = 5; //[0:Plain,1:Hole,3:Loop,5:Hook ]

linkage_hookopening_offset = -0.28 *1;
linkage_hookvertical_offset = -0.3 *1;
linkage_bottom_trim =.12;

hinge_bend_padding = .25 ;

//vertical clearance for the curve between middle section and hinges, where tendon/elastic pass
hinge_end_clearance = 1;

base_tunnel_height=.25;

//how much curved bulge to put on the plugs
hinge_plug_bulge = .2;

bumper_length_round = 2.0;

//multiplier for rounding of the hinges.  larger numbers make for less rounding. set to 0 to disable.
hinge_rounding=5.65;//hinge_rounding = 3.0; //TODO

//advanced, the clearance between rubber tip and the tip core
tip_post_clearance =.15;
//Advanced: width of the base section, beyond the middle_diameter
base_width = 4.75;
//vertical clearance for the curve between middle section and hinges, where tendon/elastic pass
//the thickness of the hinge in between the middle section and nut.
hinge_thickness = 1.4;
//Depth of the indent in the center of the middle part of hinge, allowing clearnce for the elastic or tendon
hinge_indent_depth = 0.6;

//clearance for the tunnels to the side
tunnel_clearance = .7;

tip_clearance = .15;
tip_post_height = 1.5;
tip_ridge_height = 1.5;

tensioner_nut_diam = 3.9 + .99;
tensioner_nut_thickness = 1.85;
tip_tensioner_height = tensioner_nut_diam - 0.5;
tensioner_bolt_diam = 1.95;
tip_tensioner_width = tensioner_nut_thickness * 2.0;
tip_tensioner_length = tensioner_nut_diam * 1.3;

fprint_ridge_thickness = 0.6;
fprint_ridge_offset = 1.1;
fprint_ridge_height = 1;
fprint_style = 1; //[0:disable, 1:lines, 2:concentric]

//include extra clearance for tendon string
socket_string_clearance = 0.0;//.5;

//how thick to make the built-in washers on the hinges
washer_depth_outside = .5;
//how wide to make the washers
washer_radius = 0.5;

socket_catch_height =  2;
socket_post_height =  2;

//stump indent for sphere size
stump_indent = 12.0;//socket_post_diameter*.9;
//stump indent offset for sphere
stump_indent_offset = 5.4;//1.5;

tip_fingernail_rot = 1 * -3;
tip_fingernail_offset = 1 * 2.2;
tip_cuticle_rot = 1* 60;

socket_interface_clearance_top = 0.25;
socket_interface_taper = 1.0;
socket_interface_clearance = 1.0;

socket_slot_width = 1.5;
socket_slot_depth_top = 1.0;
socket_slot_depth_bottom = 2.0;

hinge_plug_ridge_height = 0.5;
hinge_plug_side_clearance = 0.25;

 middle_diameter_width = middle_width + hinge_side_clearance*2 + hinge_thickness*6;//15
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

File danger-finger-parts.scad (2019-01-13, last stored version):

module tip(){
				hull(){
				translate([0,0,tip_cover_base_length])
				resize ([tip_top_width,0,0])
				sphere(tip_top_width/2);

				translate([0,0,0.1])
				cylinder (h=tip_cover_base_length, d1=tip_cover_width, d2=tip_top_width );//+ tip_post_clearance*2
			}
}

module nail(){
	union(){
				rotate([tip_fingernail_rot,0,0])
				translate([0,tip_fingernail_offset, tip_cover_base_length-4])
				resize ([0, tip_cover_width*1.15, tip_cover_width*2.1])
				sphere(tip_cover_width*.8);

				rotate([-15,0,0])
				translate([tip_cover_width -5,-.5,tip_cover_length/2])
				cylinder(d=tip_cover_width, h=tip_cover_length*2,center=true);

				rotate([-15,0,0])
				translate([-tip_cover_width +5,-.5,tip_cover_length/2])
				cylinder(d=tip_cover_width, h=tip_cover_length*2,center=true);

				rotate([tip_cuticle_rot,0,0])
				translate([0,0,-tip_cover_width + tip_cover_length - tip_fn_length])
				cube([tip_cover_width*2,tip_cover_width*2,tip_cover_width*2], center=true);
			}
}
//functions and model sections -- modify at own risk
module make_tipcover (){
    diame = tip_ridge_width + tip_post_clearance;
	difference(){
		intersection(){
			//plain rounded tip
			tip();

			//cut out fingernail -
			nail();

			//round fingerprint surface
			translate([0,-1.9, tip_cover_length/2-3.75	])
			rotate([5,0,0]){
				union(){
					resize ([0, tip_cover_width*1.2, tip_cover_length*1.8])
					sphere(tip_cover_width*.8);

					if(fprint_ridge_height > 0)
					intersection(){
						resize ([0, tip_cover_width*1.2 + fprint_ridge_height, tip_cover_length*1.8])
						sphere(tip_cover_width*.8);

						if(fprint_style == 1) //horiz finger prints
						translate([0,tip_cover_length/4, -tip_cover_length/2+3])
						for (i=[fprint_ridge_area +4:-fprint_ridge_offset : fprint_ridge_offset]){
							translate([0,0,i])
							cube([tip_cover_width, tip_cover_width, fprint_ridge_thickness], center=true);
						}
					}
				}
			}
		}

        //HACK - copy of fingernail stuff for inside cut out.
		//translate([0,-10,0])
       difference(){
		 resize([tip_top_width-1.0,0,0])
        	intersection(){
                translate([0,-1.8,-1.8])
				difference(){
				tip();
				//HACK
				translate([0,-3.5,0])
				cube([tip_cover_width, 1, tip_cover_length]);
				}
				translate([0,1.3,-1.8])
                nail();
            }
			//cut bottom of cut
            translate([0,0,-14 + tip_ridge_height*2+  tip_post_height])
           cylinder (h=14, d=tip_post_width*2);
			//trim top of cut
           translate([0,0,tip_cover_length-1.5])
           cylinder (h=5, d=tip_post_width*2);
		   //trim front of cut
		   //HACK 2 constant
		   translate([ 0, -tip_ridge_width/2 +2, tip_cover_length/2])
		   cube([tip_cover_width, 2, tip_cover_length], center=true);
        }

		//cut out post area
		union(){

			difference(){
				union(){
					//bottom of post
					cylinder (h=tip_post_height+1, d=tip_post_width);
					//move up a little, make bottom nice and snug
					translate([0,0, tip_post_height+tip_post_clearance]){
						//post ridge cutout
						cylinder (h=tip_ridge_height, d=diame);	//+tip_post_clearance
						//transition
						translate([0,0, tip_ridge_height -.01 ])
						cylinder (h=tip_ridge_height, d1=tip_ridge_width -1, d2=tip_pocket_width);
					}
				}
				translate([0,diame/2 +.2,tip_ridge_height+  tip_post_height+tip_post_clearance])
				cube([diame, tip_ridge_height, tip_ridge_height*2], center=true);
			}

			//laser hole
			translate([0,0, tip_post_height])
			cylinder (h=tip_length, r=tip_accessory_radius);
		}
	}
}

module make_mid_tip(){
    hinge_cutout = tip_base_length - (tip_base_length-hinge_outer_diameter/2) + hinge_side_clearance;
	difference () {
		//mainsection
		union(){
			//main section
			//hinge circles
			rotate([0,90,0])
			cylinder (d=hinge_diameter, h=middle_width, center=true);

			//post
			translate([0,0,tip_base_length +tip_post_height/2 ])
			cylinder (h=tip_post_height, d=tip_post_width-tip_clearance, center=true);
			//ridge
			translate([0,0,tip_base_length + tip_post_height + tip_ridge_height/2])
			cylinder (h=tip_ridge_height, d=tip_ridge_width-tip_clearance, center=true);

			//echo (base_total_width);
			translate([0,0,tip_base_length/2])
			cylinder (h=tip_base_length, d1=middle_diameter, d2=tip_cover_width+.25, $fn=fnv, center=true);

			//tensioner block
			if (tip_tensioner_screw_radius > 0){
				translate([0,-.25, tip_base_length + tip_post_height +tip_ridge_height +tip_tensioner_height/2])
				create_tip_tensioner();
			}
		}
		//trim SIDES
		translate([middle_width/2+.01, -hinge_diameter, -0.01])
		cube([middle_width, hinge_diameter*2, hinge_cutout], center=false);
		translate([-middle_width*1.5+.01, -hinge_diameter,-0.01])
		cube([middle_width, hinge_diameter*2, hinge_cutout], center=false);

		//elastic hole
		hull(){
			translate([-tunnel_radius-tunnel_clearance, -hinge_diameter/2 - tunnel_radius/2, 0])
			sphere(tunnel_radius);

			translate([0,-2,tip_base_length+ tip_post_height + tip_ridge_height])
			sphere(tunnel_radius);
		}

		//enlarge base side
		translate([-tunnel_radius-tunnel_clearance/2,-(hinge_diameter/2 + tunnel_radius - tunnel_clearance*1.5), tunnel_radius*2 - tunnel_radius*6])
		cylinder (r2=tunnel_radius, r1=tunnel_radius*1.5, h=tunnel_radius*6);

		//tendon hole
		hull(){
			translate([0, hinge_diameter/2 + tunnel_radius/2, 0])
			sphere(tunnel_radius);

			translate([0,1.5,tip_base_length  + tip_post_height + tip_ridge_height])
			sphere(tunnel_radius);
		}

		rotate([0,90,0]){
			//hinge pins
			cylinder (r=hinge_pin_radius, h=middle_width*2, center=true);

			//hinge indent
			translate([0,0,-tunnel_clearance]) {
				difference(){
					cylinder (r=hinge_diameter/2+.1, h=hinge_indent_width, center=true);
					union(){
						cylinder (r=hinge_diameter/2-hinge_indent_depth, h=hinge_indent_width+.1, center=true);
						translate ([-middle_width/2 ,0,0])
						cube ([middle_width, hinge_diameter,hinge_indent_width], center=true);
					}
				}
			}
		}

		//trim out bottom
		translate ([-middle_width-.05, hinge_diameter/2-.01, -tip_base_length/2-.01])
		cube([middle_width*2 +.1, middle_width, tip_base_length*2]);
	}
}

module make_tip(){
	union(){
		//cut center
		difference () {
			//mainsection
			union(){
				make_hinges();

				difference(){
					//body
					hull(){
						translate([0,0,-hinge_bend_padding])
                        resize([middle_diameter_width,0,0])
						cylinder (h=hull_cyl_height, d=middle_diameter);

                        translate([0,0,tip_base_length-hull_cyl_height])
						cylinder (h=hull_cyl_height, d=tip_cover_width + 0.2);
						//expiriment
						translate ([0, hinge_outer_diameter/2-.5, 1.25])
						cube ([ middle_width+2.5+hinge_side_clearance*2, 1, 2.5 ],center=true);	//sloppy 2.5mm
					}
					//bottom trim
					translate ([-middle_width, hinge_outer_diameter/2, -2])
					cube ([ middle_width*2, hinge_diameter/2, hinge_diameter*2 ],center=false);
                    if ( skeleton == 1){
                       translate([-middle_width/2,-10,1.5 ])
                        cube([middle_width,10,tip_base_length -3.2]);
                    }
				}
				//post
				translate([0,0,tip_base_length])
				cylinder (h=tip_post_height, d=tip_post_width-tip_clearance);
				//ridge

				translate([0,0,tip_base_length + tip_post_height])
				difference(){
					cylinder (h=tip_ridge_height, d=tip_ridge_width-tip_clearance);

					translate([0, tip_ridge_width/2 + tip_ridge_height -tip_clearance/2 - (tip_ridge_width-tip_post_width)/2,  tip_post_height - tip_ridge_height/2 - 0.0001 ])
					cube([hinge_outer_width, tip_ridge_height*2, tip_ridge_height + 0.0004], center=true);
				}

				//tensioner block
				if (tip_tensioner_screw_radius > 0){
					translate([
                    //-tip_ridge_width/2 + tip_tensioner_width*.82
                    -tip_tensioner_width/2
                    , 0
                    , tip_base_length + tip_post_height +tip_ridge_height +tip_tensioner_height/2 - 0.001]){

					create_tip_tensioner();

					}
				}
			}
			//area to cut
			union(){
				hull(){
					//back cut
					rotate([0,90,0]) {
						cylinder (d=hinge_outer_diameter+0.001, h=middle_width+hinge_side_clearance*2, center=true);
						//hinge_diameter+hinge_end_clearance*2

						//upper back cut
						translate([hinge_diameter/4,0,0])
						cylinder (d=hinge_outer_diameter, h=middle_width+hinge_side_clearance*2, center=true);
					}
				}

				//front cut
				translate ([0, hinge_diameter/2, 0])//-hinge_end_clearance])
				cube ([ middle_width+hinge_side_clearance*2, hinge_diameter, hinge_outer_diameter],true);

				//back flat cut
				rotate([0,90,0]){
					//nut hole
					cylinder (r=hinge_pin_radius, h=middle_width*3, center=true);
					// cut dips around hole for axle nuts
					get_plug_cutout();

					//TODO - rounding on outer edge
				}
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

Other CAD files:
danger-finger.scad
middle_gen.scad
output/dangerfinger_v4.2_base.scad
output/dangerfinger_v4.2_linkage.scad
output/dangerfinger_v4.2_middle.scad
output/dangerfinger_v4.2_preview.scad
output/dangerfinger_v4.2_socket.scad
output/dangerfinger_v4.2_tip.scad
output/dangerfinger_v4.2_tipcover.scad

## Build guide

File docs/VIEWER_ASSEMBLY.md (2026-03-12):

# Viewer assembly system — coordinate reference and known behaviours

This document captures how the web viewer assembles the finger from individual print-oriented STL files, and how `stl_viewer.js` transforms each mesh. It is the authoritative reference for setting `_preview_position_offsets`, `_preview_rotate_offsets`, and `_preview_plug_instances` in `danger/finger_params.py`.

> **2026-03**: `stl_viewer.min.js` (StlViewer v1.08 / Three.js r86) was replaced with `web/stl_viewer.js`, a thin wrapper over Three.js r160 + `STLLoader` r170. The transform semantics documented below are **preserved exactly** in the new wrapper.

---

## 1. The pipeline from SCAD to viewer

```
part_xxx()          -> natural/assembled geometry (SCAD coordinate space)
  |  build()
rotate(rotate_offsets[name])   -> print orientation (optimal for FDM slicing)
  |  write_file -> output/{name}.stl

HTTP: /render/{name}.stl -> browser -> stl_viewer.add_model(...)
  -> center geometry (computeBoundingBox() + translate(-center) => bbox center at local origin 0,0,0)
  -> rotate (rotateOnWorldAxis X->Y->Z by preview_rotate_offsets[name])
  -> set_position from mod_loaded (preview_position_offsets[name])
```

The viewer reconstructs the assembled finger from print-oriented STLs. Positions and rotations are viewer-only.

---

## 2. stl_viewer.js — behaviour (confirmed from source)

### 2.1 Geometry centering

After loading the STL, `stl_viewer.js` calls `geometry.computeBoundingBox()` then `geometry.translate(-center.x, -center.y, -center.z)`, which moves all vertices so the **bounding box center becomes the geometry local origin (0,0,0)**. This replicates the old `geometry.center()` behavior exactly. The original SCAD/STL coordinate system is discarded.

**Consequence**: `_preview_position_offsets` values must be the world-space position of each part's bounding box center in assembled finger space — not SCAD translate offsets.

### 2.2 Rotation

Rotation is applied via `mesh.rotateOnWorldAxis(axis, angle)` (Three.js r160+), which pre-multiplies the mesh matrix by a world-space rotation. This is equivalent to the old `rotateAroundWorldAxis(mesh, worldAxis, angle)`. Because geometry was centered first, this effectively **rotates around the part's own center**. Values are applied as successive X → Y → Z world-axis rotations (in degrees; `index.html` calls `degtorad`).

### 2.3 Position ordering — the mod_loaded override

`set_model_custom_props` (synchronous in `add_model`):
1. Sets `mesh.position` from `add_model` params.
2. Calls `rotate(...)`.

`mod_loaded` (async callback when STL loads):
3. Calls `set_position(id, pos[0], pos[1], pos[2])` — **overrides** position with `preview_position_offsets`.

Net effect: geometry is centered, rotated around its own center, then translated to `preview_position_offsets`.

### 2.4 DEBUG_PREVIEW_SCALE is a no-op

`add_model` multiplies position by `DEBUG_PREVIEW_SCALE`, but `mod_loaded` always overrides with the unscaled value. Has no visual effect.

---

## 3. How assembled positions are derived

The correct `_preview_position_offsets[name]` is the **world-space location of the bounding box center of `name` in assembled (natural/pre-print-rotation) orientation**.

### 3.1 Natural assembled coordinate system

The finger's natural coordinate space (pre-print-rotation, default params):

| Part | Y span (approx)  | Bbox center Y |
|---|---|---|
| socket | -46 to -5 | approx -25 |
| base | -11 to +5 | approx -3 |
| middle | -5  to +29 | approx +12 |
| tip | +19 to +33 | approx +26 |
| tipcover | +30 to +48 | approx +39 |
| linkage  | centered Y=0, Z offset=+20 | approx (0,-3,20) |

Y=0 is the **proximal hinge** (where base meets middle).

`part_tip()` returns `final.translate((0, intermediate_length, 0))` — this translation is **baked into the geometry** before print rotation, so the tip's natural bounding box starts at Y approx `intermediate_length`.

### 3.2 Correct values from v5.1 STL measurements

v5.1 STLs were in natural/assembled orientation (no print rotations) and serve as ground-truth:

```
socket:   center approx (0.1, -24.8, -0.1)
base:     center approx (0.0,  -2.7,  0.0)
middle:   center approx (1.0,  11.6,  0.0)
tip:      center approx (1.2,  26.3,  0.0)
tipcover: center approx (0.0,  39.0,  0.0)
```

These scale with `intermediate_length` and other params. Ideally derived dynamically from built geometry.

---

## 4. Preview positions — fix applied (v5.3 / 2026-03)

`_preview_position_offsets` updated to assembled bbox centers from section 3.2. The legacy 35 degree Z rotation was removed from tip and tipcover in `_preview_rotate_offsets` (it matched `preview_rotate=True` SCAD behaviour, not the current `preview_rotate=False` reference).

`compute_preview_positions()` was also corrected after bugs were found where it placed tip 10 mm too high and socket 5 mm too low. The correct formulas, derived from Y-span midpoints (section 3.1):

| Part | Formula (Y center) | Default |
|---|---|---|
| base | `-(prox_len + prox_h/2) / 2` | −2.5 |
| middle | `int_len / 2` | 12.0 |
| tip | `int_len + distal_base_len / 2` | 27.0 |
| tipcover | `int_len + (distal_base_len + dist_len) / 2` | 39.0 |
| socket | `-(prox_len + prox_h/2 + flange_h + (sock_iface_len + sock_depth − SCALLOP_HEIGHT/2) / 2)` | −24.2 |
| stand | `socket_y − sock_depth * 0.15` | −29.3 |

Key bug: the original formula used `dist_len/2` for the tip (= 12 mm offset) instead of `distal_base_len/2` (= 3 mm), conflating the tipcover dome length with the rigid hinge section.

---

## 5. SCAD all view vs viewer

### The preview_rotate flag

`preview_rotate = False` is hard-coded in `finger_params.py`. With this flag:
- `_part_composite` skips `_rotate_offsets["all"]` per-part rotations and the tip special transform.
- Parts appear in natural/assembled orientation at `translate_offsets["all"]` (mostly zeros).
- The output PNG (`dangerfinger_v*_all.png`) is the canonical visual reference.
- The diagonal appearance is OpenSCAD's default camera angle, not a physical rotation.

---

## 6. How preview_rotate_offsets is derived

Each part's print rotation is in `_rotate_offsets[name]` (single tuple). The preview rotation is the approximate inverse.

| Part | Print rotation | Preview rotation | Notes |
|---|---|---|---|
| socket | (-90, 0, 0) | (+90, 0, 0) | |
| base | (+90, 0, 0) | (-90, 0, 0) | |
| tip | (-90, 0, 0) | (+90, 0, 0) | legacy 35 deg Z removed |
| tipcover | (+90, 0, 0) | (-90, 0, 0) | legacy 35 deg Z removed |
| linkage  | (0, -180, 0) | (0, +180, 0) | |
| middle | (90, -50, 90) | (-90, +50, -90) | multi-axis; true inverse is non-trivial |

For multi-axis Euler rotations, negating each component is approximate. Verify visually.

---

## 7. OpenSCAD on macOS ARM64

Qt runtime check fails on native ARM64. Fix in `danger/Scad_Renderer.py`: prepend `arch -x86_64` on `darwin/arm64` (Rosetta 2). Disable with `OPENSCAD_USE_ROSETTA=0`. Headless PNG needs Xvfb (`DISPLAY=:99`).

---

## 8. Plug instances

Single STL (`plug.stl`) displayed four times via `compute_preview_plug_instances()` (dynamic, from params) falling back to `_preview_plug_instances` for the initial page load.

Position formulas:
- `prox_z = -(knuckle_proximal_width/2 - knuckle_plug_thickness/2) - 0.01`  (outer face of proximal hinge)
- `dist_z = -(knuckle_distal_width/2 - knuckle_plug_thickness/2)`  (outer face of distal hinge)
- Y = 0 (proximal hinge axis) or `intermediate_length` (distal hinge axis)

Default values: proximal `Z = ±8.61`, distal `Z = ±7.35`.

---

## 9. Pins — excluded from preview

`part_pins()` writes both hinge pins into a **single composite STL** at local Y=0 (proximal) and Y=`pins_translate_y` (=10, not `intermediate_length`). After bbox-centering in the viewer the pins land at Y=±5 — completely wrong. `viewer.js` skips loading `pins.stl` via `PREVIEW_SKIP_PARTS`. Pins are still included in the download bundle for printing.

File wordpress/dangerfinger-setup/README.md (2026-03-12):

# DangerFinger WordPress Setup

> **Status (2026-03-12)**: All steps below have been applied to dangercreations.com
> via SSH. This README is kept as reference for future re-installs, theme changes,
> or migrations. See `.cursor/rules/wordpress-integration.mdc` for the live
> connection details and gotchas.

This directory contains everything needed to integrate the DangerFinger app
(hosted on AWS) with the WordPress site on SiteGround.

## Auth flow overview

```
User (browser)
  │  1. Click "Login" in the app
  ▼
WordPress /wp-admin/authorize-application.php
  │  2. User logs in (if not already), approves the app
  ▼
App URL?jwt_auth=1&user_login=...&password=...
  │  3. App POSTs to /wp-json/jwt-auth/v1/token with Application Password
  ▼
JWT token returned → stored in sessionStorage
  │  4. App sends Authorization: Bearer <JWT> on protected requests
  ▼
Tornado server validates JWT locally (no WP round-trip per request)
```

## Setup steps

### 1. Install the JWT plugin

In WP Admin → Plugins → Add New, search for and install:
**"JWT Authentication for WP REST API"** by Enrique Chavez

### 2. Update wp-config.php

Add the lines from `wp-config-additions.txt` to `/public_html/wp-config.php`
before the "That's all, stop editing!" line.

**Important**: Set `JWT_AUTH_SECRET_KEY` to a random 32+ character string,
and use the **same secret** as the `jwt_secret` env var in the Tornado server
(see `docker/env-example.txt`).

### 3. Update .htaccess

Add the rules from `htaccess-additions.txt` to `/public_html/.htaccess`,
**after** the `# END WordPress` block (not inside it — WordPress overwrites
that section on permalink save).

> **Note**: SiteGround's default WordPress `.htaccess` already includes
> `RewriteRule .* - [E=HTTP_AUTHORIZATION:%{HTTP:Authorization}]` inside the
> WordPress block, so the Authorization header passthrough works out of the box.
> The additions in `htaccess-additions.txt` are for security blocks only
> (user enumeration, XML-RPC, version disclosure).

> **Caveat**: SiteGround uses nginx in front of Apache. nginx serves static
> files directly, bypassing `.htaccess`. To block a static file like
> `readme.html`, **delete it** rather than relying on `FilesMatch`.

### 4. Add PHP code to functions.php

Add the contents of both PHP files to your active theme's `functions.php`
(or create a custom must-use plugin under `wp-content/mu-plugins/`):

- `functions-security.php` — security hardening (user enumeration, EXIF, etc.)
- `functions-auth.php` — JWT payload filter + `[dangerfinger_configurator]` shortcode

### 5. WordPress admin changes

- **Disable open registration**: Settings → General → uncheck "Anyone can register"
- **Fix HTTPS**: Settings → General → ensure WordPress Address and Site Address both use `https://`
- **Consolidate form plugins**: keep only one of Ninja Forms / Pirate Forms / WPForms;
  deactivate and delete the others from Plugins → Installed Plugins

### 6. Create the configurator page

Create a new WordPress Page at permalink `/prosthetics/configure` with this shortcode:

```
[dangerfinger_configurator url="https://YOUR_AWS_APP_URL"]
```

### 7. Verify the JWT endpoint

```bash
curl -X POST https://dangercreations.com/wp-json/jwt-auth/v1/token \
     -H "Content-Type: application/json" \
     -d '{"username":"YOUR_USERNAME","password":"YOUR_APP_PASSWORD"}'
```

Expected response:
```json
{
  "token": "eyJ...",
  "user_email": "you@example.com",
  "user_nicename": "your-username",
  "user_display_name": "Your Name"
}
```

### 8. Configure the Tornado server

Set these environment variables (see `docker/env-example.txt`):

```
jwt_secret=SAME_KEY_AS_JWT_AUTH_SECRET_KEY_IN_WP_CONFIG
wp_auth_url=https://dangercreations.com
app_base_url=https://YOUR_AWS_APP_URL
```

## Files in this directory

| File | Purpose |
|---|---|
| `README.md` | This file |
| `functions-security.php` | WP security hardening |
| `functions-auth.php` | JWT filter + shortcode |
| `htaccess-additions.txt` | Security blocks (user enum, XML-RPC, version disclosure) |
| `wp-config-additions.txt` | JWT plugin config + HTTPS + app URL |

## Live configuration reference

These values are currently set on dangercreations.com:

- **JWT plugin**: JWT Authentication for WP REST API v1.5.0 (active)
- **Active theme**: kale (functions.php has all filters + shortcode)
- **Configure page**: `/prosthetics/configure` (page ID 1227, child of Prosthetics ID 9)
- **siteurl / home**: `https://dangercreations.com`
- **users_can_register**: `0` (disabled)
- **Deactivated plugins**: `pirate-forms`, `wpforms-lite` (kept `ninja-forms`)
- **Deleted files**: `readme.html`, `license.txt` (version disclosure)
- **Blocked via .htaccess**: `?author=N` enumeration, `xmlrpc.php`
- **Blocked via PHP filter**: `/wp-json/wp/v2/users` (REST user enumeration)

SSH access and gotchas are documented in `.cursor/rules/wordpress-integration.mdc`.

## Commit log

2017-06-02 Updates to comments
    [config_nbrookins.scad, danger-finger.scad]
2019-01-13 prototype of major new version
    [danger-finger-defaults.scad, danger-finger-parts.scad, danger-finger.scad]
2019-12-30 Python based version
    [config_nbrookins.scad, danger-finger-defaults.scad, danger-finger-parts.scad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]
2019-12-30 temp file
    [middle_gen.scad]
2020-01-03 added socket interface
2020-02-08 pre-computed output
    [dangerfinger_v4.2_base.scad, dangerfinger_v4.2_base.stl, dangerfinger_v4.2_linkage.scad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]
2020-03-08 web fixes
    [dangerfinger_v4.2_base.scad, dangerfinger_v4.2_base.stl, dangerfinger_v4.2_linkage.scad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]
2020-04-12 finger improvements and api & web advancements
2026-03-11 Replace 17 magic-number constants with parametric derivations
    Each constant is now computed from existing parameters (e.g.
    BRIDGE_WIDTH=3 -> knuckle_distal_thickness, TENDON_CUT_X=19.2 ->
    socket_depth/2 + tendon_hole_width). Derivations preserve identical
    default geometry while enabling proper parametric scaling.
    Deferred: PEG_SUPPORT_RADIUS, PEG_SUPPORT_SIDE_X_OFFSET,
    PEG_SUPPORT_TRANSLATE_Z, SCALLOP_HEIGHT (no clean derivation yet).
    Made-with: Cursor
2026-03-11 Fix UI encoding, dynamic part buttons, traceable Docker builds
    - Add <meta charset="utf-8"> and align title/h1 to use en-dash entity,
    fixing mojibake in headless screenshot and browser tab
    - Replace hardcoded 4-button part row with #part_buttons_container;
    add _fill_part_buttons() populated from /api/parts so all 9 parts
    (tip, middle, base, linkage, tipcover, socket, plug, stand, pins)
    get toggle buttons instead of just the original 4
    - Make `parts` and `partNameToId` dynamic — populated in
    apply_preview_config() from /api/parts response; hardcoded init removed
    - Update BUILD_NUMBER default in Makefile to include git short SHA
    (e.g. dev-abc1234) so each Docker image tag is trac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
2026-03-11 Implement missing UX plan features: params redesign, EnumOptions, explode offsets, version
    fill_params() rewrite:
    - Bootstrap table (table-sm table-bordered) with # / Parameter / Value /
    Default / Min-Max / Description columns replacing the old ad-hoc table
    - <select> dropdown for enum-typed parameters (e.g. intermediate_bumper_style
    shows NONE/MINIMAL/COVER/FULL instead of a freetext field)
    - 'modified' badge (badge-warning) on value cell when changed from default
    - table-warning row highlight when any param is dirty
    - Collapsible Advanced section with alert-warning banner explaining risk
    - Save-as row (label + input + button) stays inside the Standard form
    _update_param_row() helper k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
2026-03-11 Fix three bugs found in refactor: charset, plug instance visibility
    1. Add back <meta charset='utf-8'> to index.html - dropped in refactor
    commit, needed for any non-ASCII chars in param Documentation strings
    and JS source files with unicode literals.
    2. Plug instances (IDs 100-103) not removed/re-added when toggling plug
    visibility. app.js onPartToggle now calls Viewer.setPlugVisibility()
    for the 'plug' part, which removes/re-spawns all four hinge peg instances.
    3. viewer.js: expose setPlugVisibility(visible, partVisibility) so app.js
    can coordinate plug + instances as a single logical unit, keeping modules
    decoupled (partVisibility passed in, not pulled from Params dire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
2026-03-11 Re-fix floatify/remove_defaults enum crash, update inspect_ui for new DOM
    The refactor commit reverted the two server.py enum-handling fixes:
    - floatify() lambda crashed on float('COVER') for BumperStyle params
    - remove_defaults() crashed on float(BumperStyle.COVER) comparison
    Both are restored with try/except fallback to string comparison.
    inspect_ui.py updated for refactored DOM:
    - Title/H1 check accepts both 'Danger Finger' and 'DangerFinger' formats
    - Toggle check looks for #toggle_{id} checkboxes (new) AND #b_{id} buttons (old)
    - Advanced collapse check looks for Bootstrap [data-toggle='collapse'] link
    targeting #advancedParams as well as the old #b_pa button
    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
2026-03-12 fix: restore plug instances, center on hinges, explode horizontally
    - viewer.js: save plug URL before skipping addModel (was in
    PREVIEW_SKIP_PARTS which prevented URL caching, breaking all
    plug instances); apply plug color from previewConfig; explode
    plugs along Z (horizontal) instead of Y (vertical)
    - finger_params.py: add knuckle_plug_radius to plug instance Y
    positions so plugs visually center on hinge faces after the
    viewer's bbox-center pipeline
    - server.py: restore FingerPart.PLUG in parts list (was removed,
    preventing plug.stl from rendering); add IndexHandler for
    build-ID cache busting; remove FingerPart.PINS from parts list
    - app.js: restore plug entry in parts map (id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
2026-03-12 feat: WordPress JWT auth integration
    - web/auth.py: JWT validation with local secret + LRU cache
    - web/server.py: WpAuthMixin, protect render/profile write endpoints
    - web/app.js: full auth flow, sessionStorage, login/logout UI
    - web/api.js: Bearer token injection, fetchWpJwt()
    - web/params.js: auth gate in submit(), setUsername()
    - web/index.html: auth bar with login/logout/user display
    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
    [wp-config-additions.txt]
2026-03-12 cors and such
    [wp-config-additions.txt]
2026-03-16 UX overhaul: async preview, param ordering, render intelligence, share links
    Async preview queue (PRIORITY_PREVIEW=-10, in-memory results, frontend
    polling), deterministic param ordering with Common/Standard/Advanced
    sections, render button intelligence tracking _lastRenderedCfghash,
    iframe full-page launch and shareable config links via URL hash, profile
    table render status column, per-param and global reset-to-defaults,
    quality indicator, and preset configurations dropdown.
    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
2026-04-09 Enhance G-code processing with optional speed and temperature adjustments. Added M220 feedrate control, F-word scaling, and temperature overrides during print phases. Introduced `--inspect` feature f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
2026-04-12 Enhance development environment and testing capabilities
    - Updated `.gitignore` to exclude `.dev-server.json`.
    - Expanded `Makefile` with new targets for local development: `start-dev`, `serve-local`, and `visual-review`.
    - Introduced `bin/dev-server` to run OpenSCAD and Chromium services outside the sandbox for improved testing.
    - Added `bin/openscad-local` as a CLI wrapper for OpenSCAD, allowing HTTP-based rendering.
    - Updated `requirements-dev.txt` to include `trimesh` and `numpy` for enhanced geometry validation.
    - Created `prompt.md` to document project overview, stack, key entry points, and testing philosophy.
    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
